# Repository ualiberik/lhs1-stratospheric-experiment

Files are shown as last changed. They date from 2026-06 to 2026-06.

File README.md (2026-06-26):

# LHS-1 Stratospheric Experiment: 26.073B

## Overview
This project is the stratospheric experiment for a high-altitude balloon flight. The experiment studies thermal insulation efficiency of lunar regolith (simulant) collecting important data for the future colonization of the Moon. The experiment was selected by iEDU Cubes in Space program for the flight on the NASA RB-11 high-altitude balloon.

&nbsp;

<div align="center">
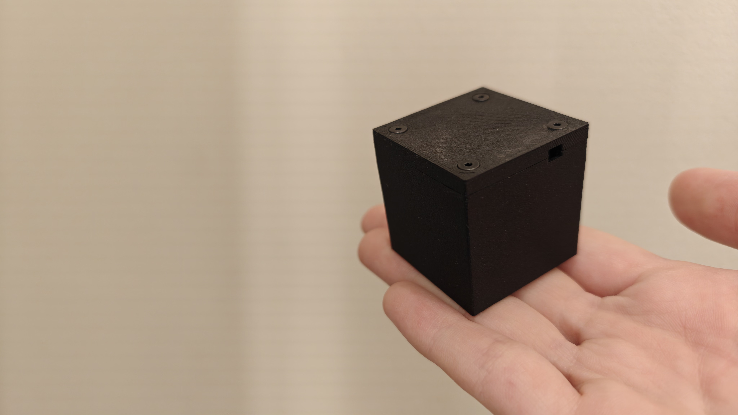
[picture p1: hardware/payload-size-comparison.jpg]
Payload Cubes Size Comparison
  
  <br>
  <em>Payload Cube Size Comparison</em>
</div>

&nbsp;

## Status
The ground experiments were conducted and the payload cube is fully ready for flight.

## Experiment Title
Thermal Insulation Efficiency of LHS-1 Lunar
Regolith Simulant as a Material for Lunar Habitats
in Stratospheric Near-Vacuum Conditions.

## Problem Statement
NASA and all the international space agencies highly
advocate the use of In-Situ Resource Utilization (ISRU), especially utilizing the lunar regolith as the main
material in the 3D printing of habitats. 

The main problem with the use of regolith in this regard is the alteration
in the thermal insulation capabilities of the regolith when it is exposed to vacuum conditions. This makes
regolith potentially an excellent insulator, but its exact performance in near-vacuum has not been sufficiently
tested under dynamic flight conditions on Earth. 

This gap is confirmed by reliable sources: Exolith Lab
(2023) LHS-1 Lunar Highlands Simulant Fact Sheet, NASA (2022) Lunar Surface Innovation Initiative – ISRU
Focus Area, and Zacny et al. (2012) “Lunar Regolith Mechanics and Its Relevance to ISRU” (Earth and Space
2012, ASCE).

## Hypothesis
_**IF**_ a high-accuracy temperature sensor (+-0.25°C accuracy, MCP9808) exposed to extremely low
temperatures (-50 °C to -60°C) and near-vacuum atmospheric pressure (0.01 ~ 0.1 atm corresponding to 15 -
25 km altitude) during a stratospheric balloon flight is shielded by 3-8 mm of lunar highlands regolith simulant
(LHS-1, with bulk density ~1.6 g/cm3),

_**THEN**_ the temperature drop under the protection of the regolith will be at least 30 - 50% slower (over a multi-hour exposure period), compared to an unprotected ambient sensor (BMP-388), proving the usefulness of
lunar regolith as a thermal insulation and shielding material for lunar surface bases,

_**BECAUSE**_ the extremely low atmospheric pressure (0.01 atm) will remove air between regolith particles,
significantly decreasing the efficiency of convective heat transfer and the overall thermal conductivity of the
regolith.

## Variables

### Independent Variables
1. **External temperature (°C):** BMP-388 sensor measures it during flight. It directly affects the
under-regolith temperatures and launches the cooling process, imitating nightfall on the Moon.

2. **Atmospheric pressure (Pa):** BMP-388 sensor measures it during flight. The decrease of atmospheric
pressure brings experiment closer to the lunar conditions and affects regolith’s thermal insulation
properties.

The experiment has 2 independent variables. However, they do not interfere with each other: the decrease of
external temperature is a trigger of cooling. Analysis compares it with under-regolith temperature, while the
atmospheric pressure defines how effectively the regolith shield works.

### Dependent Variables
1. **Under-regolith temperature (°C):** MCP9808 temperature sensor measures it during flight. It is the
internal temperature isolated by the regolith shield.

## Methodology

5 datasets will be collected:

1. **The flight dataset** — main data collected from the RB-11 flight in stratospheric conditions.

2. **No regolith configuration (atmosphere)** — defines baseline difference between sensors in 1 atmosphere conditions.

3. **No regolith configuration (near-vacuum)** — defines baseline between sensors in vacuum chamber conditions.

4. **Regolith configuration (atmosphere)** — defines regolith's contribution to thermal conductivity in 1 atmosphere conditions.

5. **Regolith configuration (near-vacuum)** — defines regolith's contribution to thermal conductivity in vacuum chamber conditions — the most close to the real flight test.

## Experiment Design

The experiment studies thermal insulation properties of lunar regolith simulant LHS-1 in stratospheric
conditions being launched on a balloon. The experiment components will be divided into 3 groups:

1. **Basic electronics group** — includes Adafruit ESP32-S3 microcontroller and Li-ion Charger. It controls
other electronics, saves data, and supplies power. ESP32-S3 microcontroller collects and writes data
once a second during flight and saves it on its own.

2. **Experimental group** — includes Adafruit MCP9808 temperature sensor and LHS-1 (Lunar Highlands
Simulant, then will be called “regolith”, “simulant”, “lunar dust”, etc.) shield. Sensor measures
dependent variable (under-regolith temperature). The regolith shield represents the main point of the
experiment, covering the sensor and protecting it from cooling.

3. **Control group** — includes Adafruit BMP388 atmospheric pressure and temperature sensor. It measures
independent variables (external temperature, atmospheric pressure) and plays the role of a control
group being not protected by a regolith shield.

The 3D-printed PET-G (Polyethylene Terephthalate Glyco — one of the plastics used for 3D-printing) cube payload cube contains all 3 groups providing construction rigidity and allowing mount components.

&nbsp;

<div align="center">
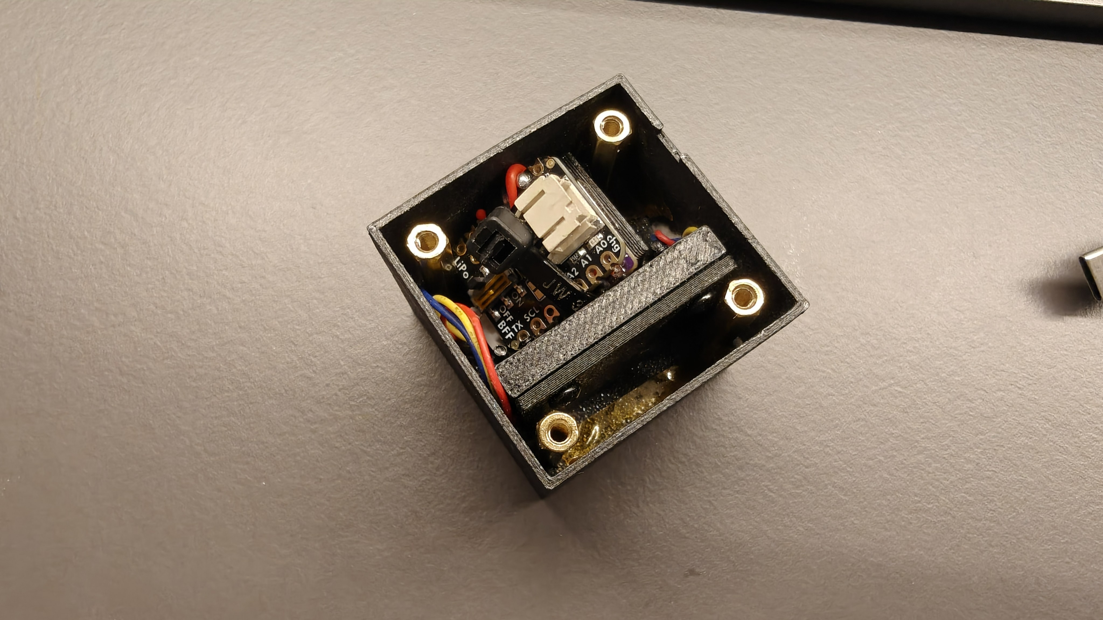
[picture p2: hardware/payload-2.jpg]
Payload Cube with Lid Opened
  
  <br>
  <em>Payload Cube with Lid Opened</em>
</div>

&nbsp;

## Repository Structure
```text
lhs1-stratospheric-experiment/
├── README.md
├── LICENSE
├── firmware/
│   ├── ion_2026_berikov/     # main flight firmware
│   ├── flashutil/            # flash management
│   └── ion_flash_dumper/     # data download
├── cad/
│   ├── stl/
│   ├── step/
│   └── renders/
├── hardware/
├── data/
│   ├── exp01-flight/
│   ├── exp02-no-reg-atm/
│   ├── exp03-no-reg-vac/
│   ├── exp04-reg-atm/
│   └── exp05-reg-vac/
├── analysis-scripts/
├── docs/
│   ├── results-summary.md
│   └── experiment-configs/
└── assets/
```
## Author Contributions
1. **Uali Berik** — Conceptualization, Methodology, Mechanical design (CAD),
   Software (firmware), Hardware integration, Validation, Writing,
   Project administration.

2. **Arlan Tairov** — Problem statement, Background research.

3. **Amina Toxankyzy** — Communication plan, Documentation of assembly process.

4. **Nurzhan Kunakbayev** — Safety, Analysis plan.

5. **Arman Temirbulatov** — Assembly support.

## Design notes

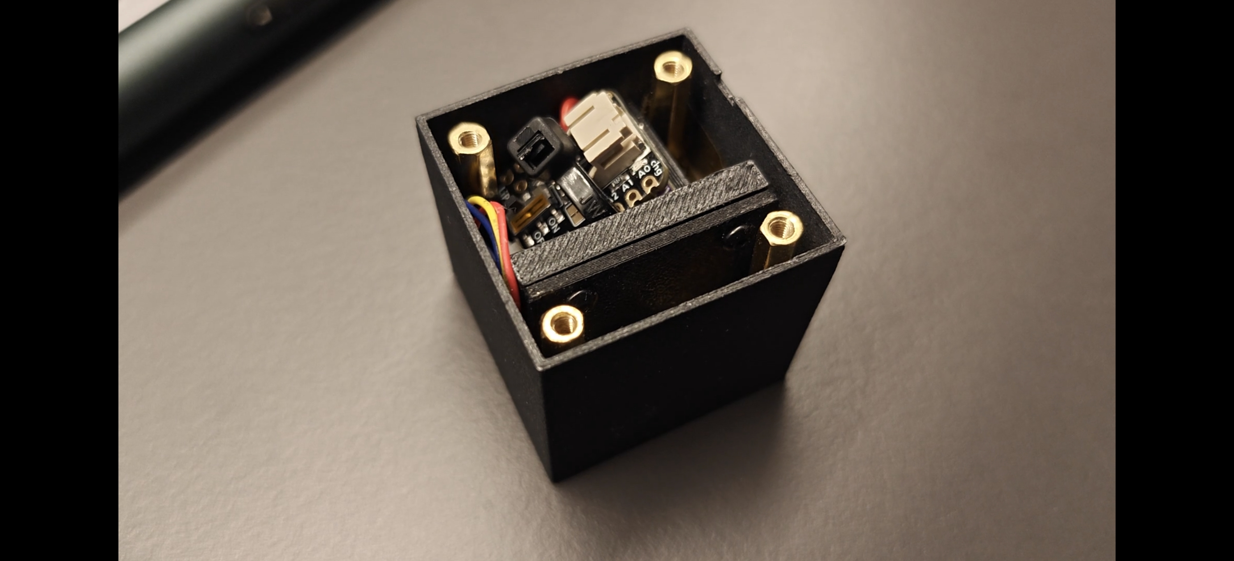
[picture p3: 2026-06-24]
hardware/payload-1.jpg

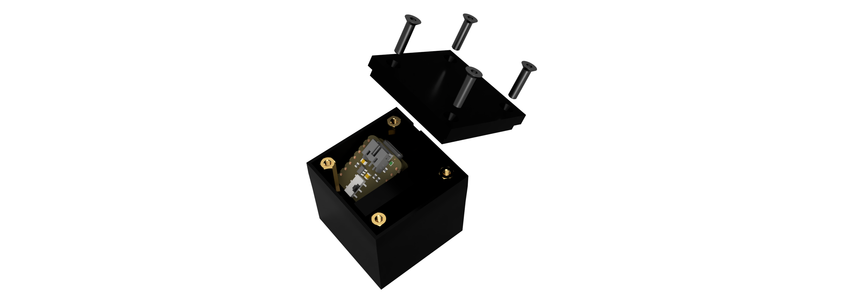
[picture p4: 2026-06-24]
cad/renders/lid-opened.png

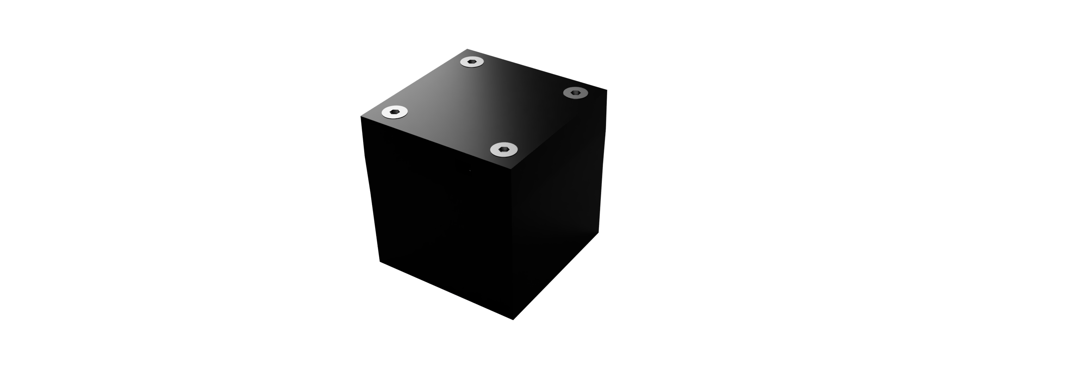
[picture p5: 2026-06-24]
cad/renders/payload-cube.png

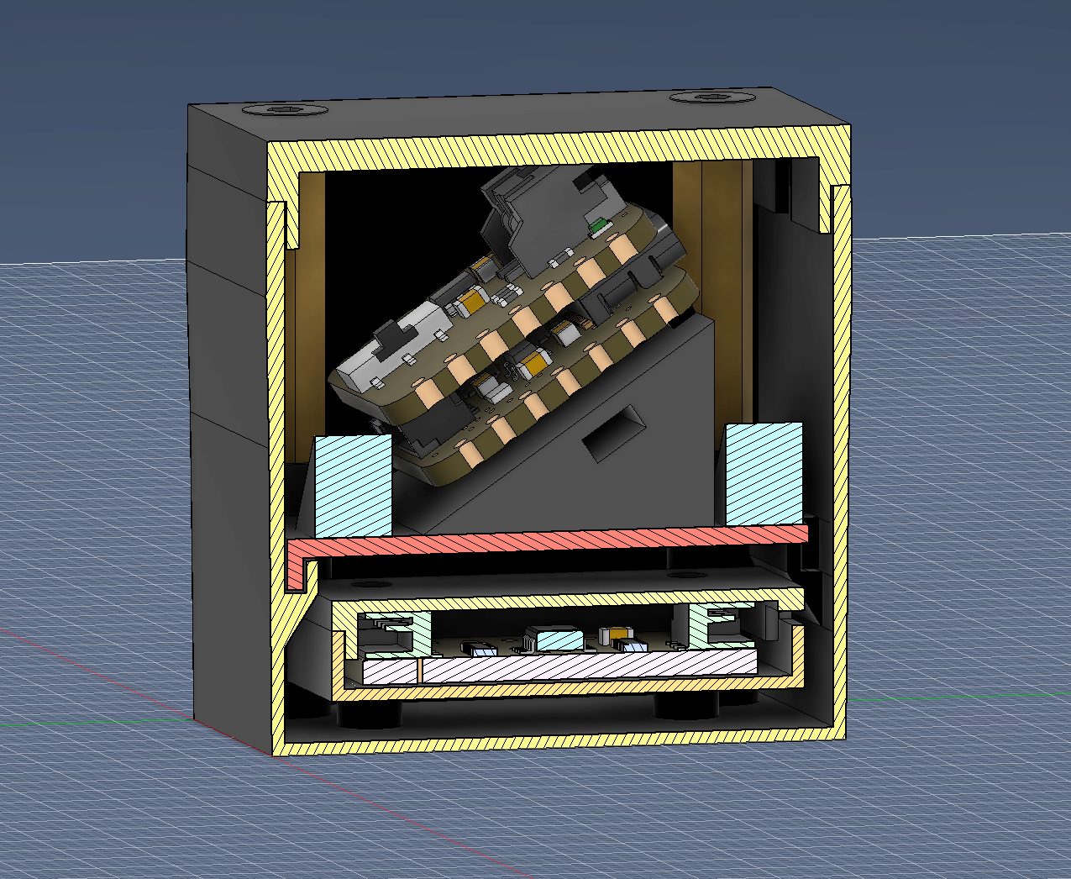
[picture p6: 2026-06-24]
cad/renders/payload-cube-in-section.png

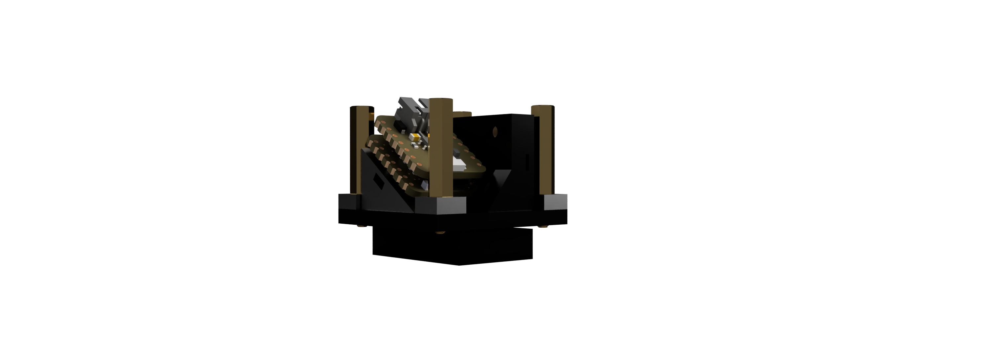
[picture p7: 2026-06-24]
cad/renders/payload-cube-inside.png

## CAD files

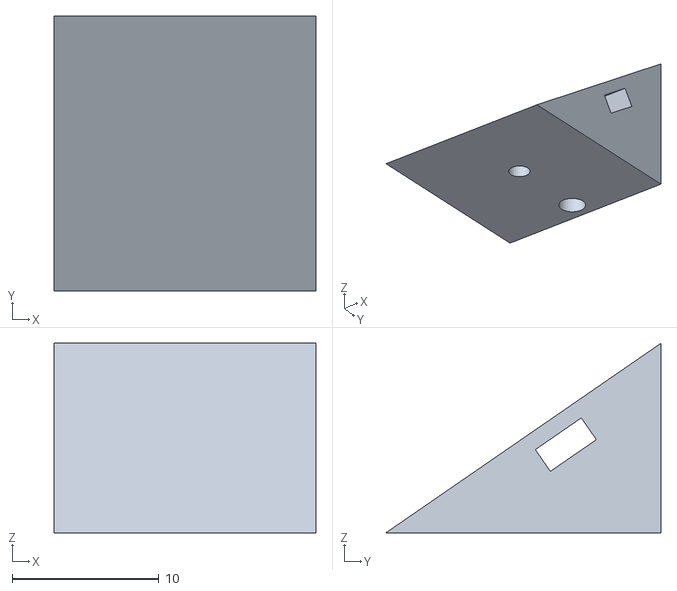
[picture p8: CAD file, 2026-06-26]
cad/stl/rack.stl
17.8 x 18.7 x 12.9

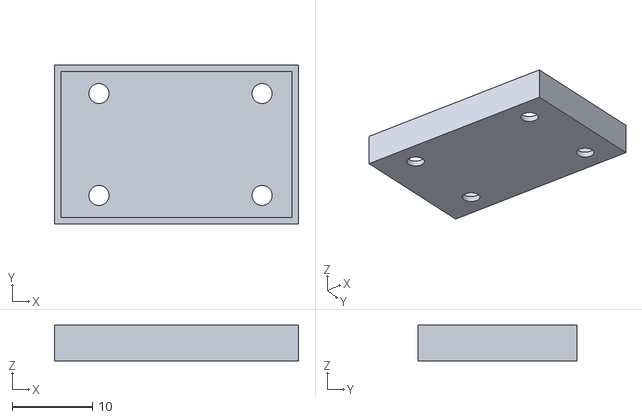
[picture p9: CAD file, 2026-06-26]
cad/stl/mcp-capsule.stl
30.4 x 19.8 x 4.43

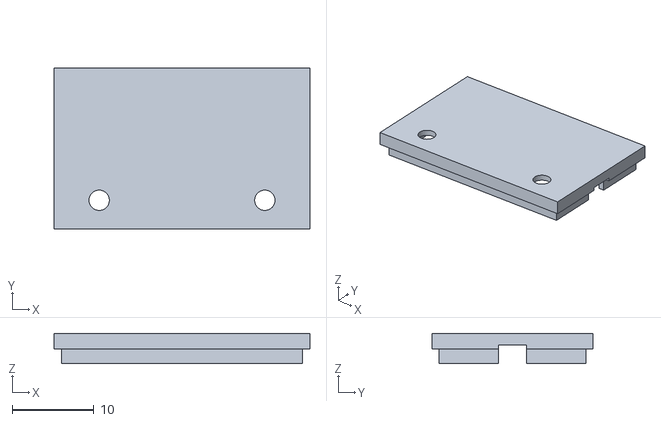
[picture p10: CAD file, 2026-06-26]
cad/stl/bmp-capsule-lid.stl
31.4 x 19.8 x 3.70

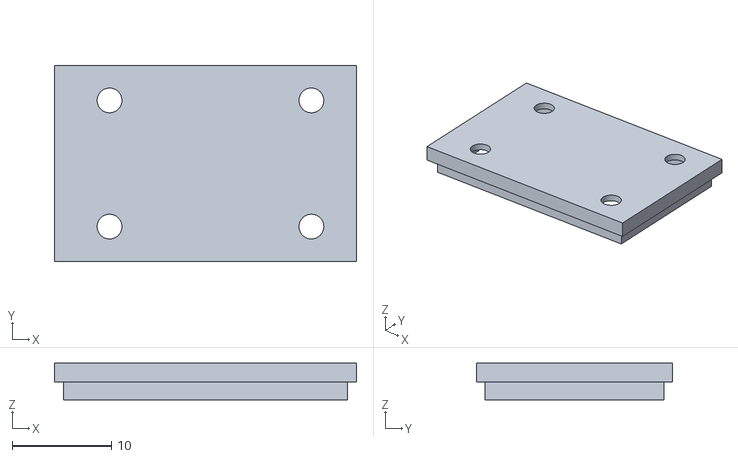
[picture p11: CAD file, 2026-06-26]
cad/stl/mcp-capsule-lid.stl
30.4 x 19.8 x 3.70

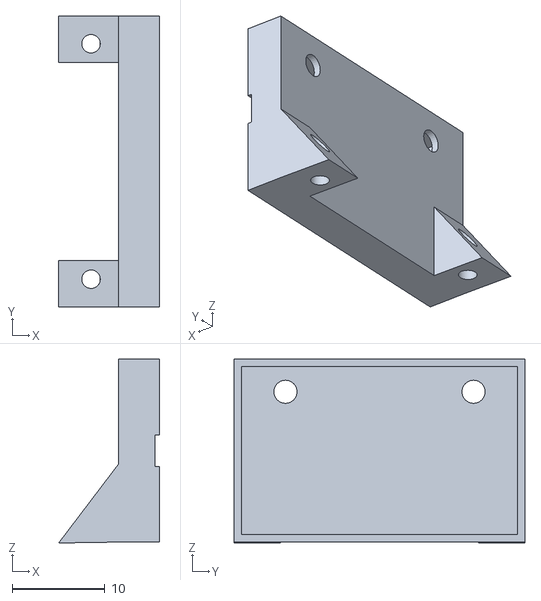
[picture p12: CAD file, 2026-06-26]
cad/stl/bmp-capsule.stl
10.9 x 31.4 x 19.9

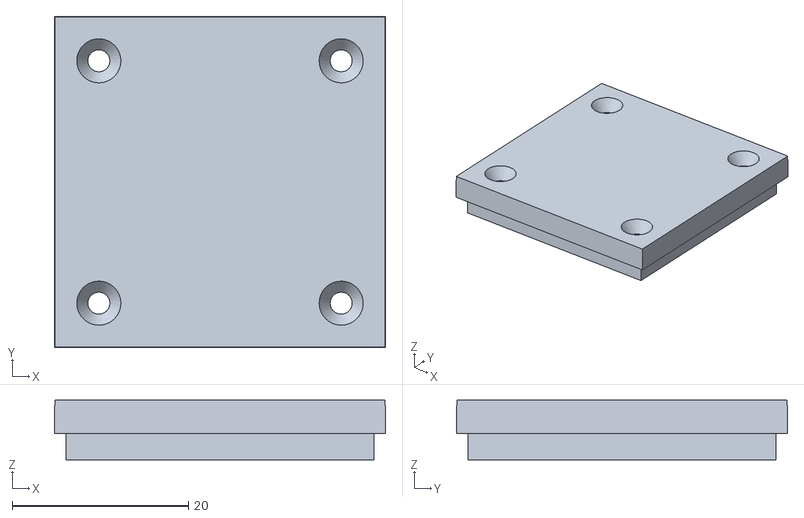
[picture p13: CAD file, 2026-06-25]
cad/stl/payload-cube-lid.stl
37.6 x 37.6 x 6.80

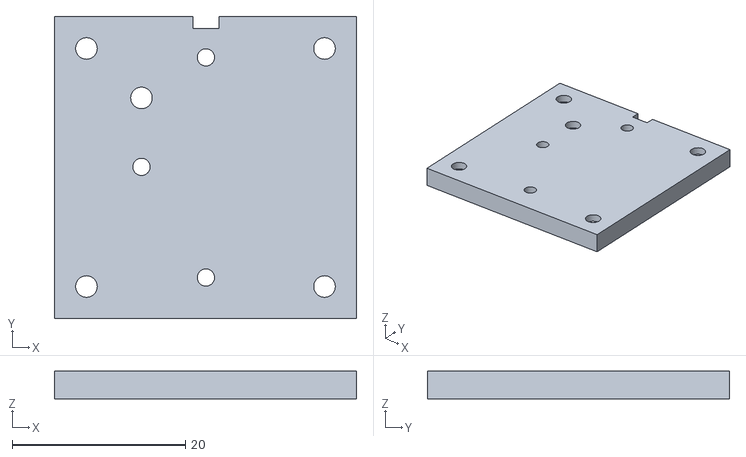
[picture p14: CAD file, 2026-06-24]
cad/stl/Plate.stl
34.9 x 34.9 x 3.20

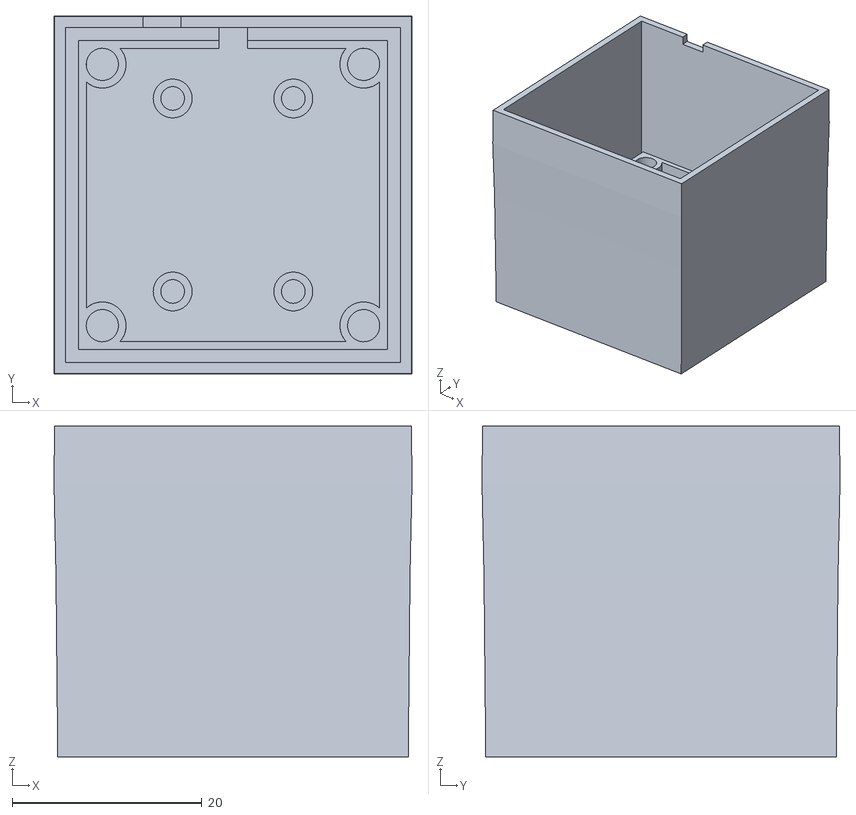
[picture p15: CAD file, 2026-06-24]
cad/stl/payload-cube.stl
37.7 x 37.7 x 34.8

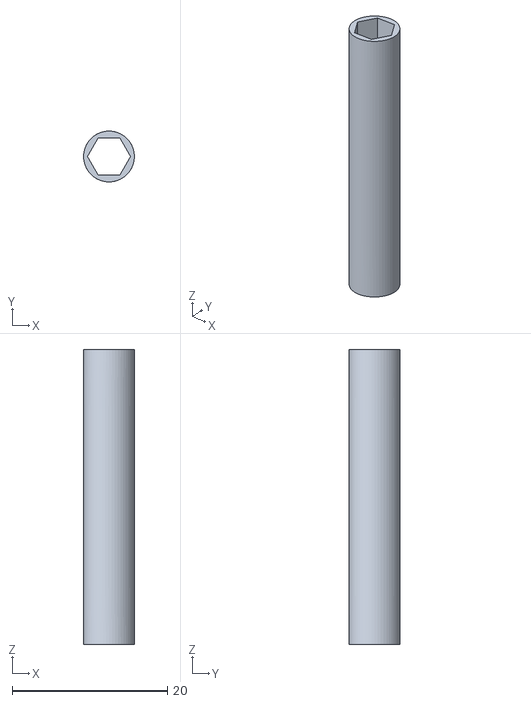
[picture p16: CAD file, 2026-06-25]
cad/stl/standoff-screwer.stl
6.55 x 6.55 x 38.0

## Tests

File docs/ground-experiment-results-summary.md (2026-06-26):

# LHS-1 Regolith Thermal Insulation — Ground Experiment Results

## Overview

Four bench experiments were conducted to characterize the thermal insulation effect of
LHS-1 Lunar Highlands Simulant regolith under atmospheric and near-vacuum conditions.
Cooling curves were fitted to Newton's law of cooling:

```
T(t) = T_amb + A × exp(−t / τ)
```

The primary metric is the **insulation ratio R = τ_mcp / τ_bmp**, where:
- τ_mcp — cooling time constant of the MCP9808 sensor (under regolith, or exposed)
- τ_bmp — cooling time constant of the BMP388 sensor (external reference)

R > 1 means the regolith-shielded sensor cools slower than the reference → insulation effect.

## Hardware

| Config | MCU | Firmware |
|---|---|---|
| EXP-04, EXP-05 | Adafruit ESP32-S3 Feather | ion_2026_berikov |
| EXP-02, EXP-03 | ESP32-C6 SuperMini | ion_no-regolith_c6 |

**Burst structure:** 60 s awake (600 samples at 100 ms) → 60 s sleep → repeat. Cycle = 120 s.

## Results

| Experiment | Conditions | τ_bmp (s) | τ_mcp (s) | R |
|---|---|---|---|---|
| EXP-02 | No regolith, atmosphere | 645 ± 13 | 645 ± 19 | **0.999** |
| EXP-04 | Regolith, atmosphere | 937 ± 14 | 1021 ± 24 | **1.090** |
| EXP-03 | No regolith, near-vacuum (~20 hPa) | 751 ± 15 | 709 ± 18 | **0.945** |
| EXP-05 | Regolith, near-vacuum (~25 hPa) | 879 ± 15 | 905 ± 27 | **1.029** |

EXP-04: 4 runs performed; run 4 used for final fit.  
EXP-05: run 1 discarded (unstable vacuum); run 2 used.

## Key Findings

**Net regolith contribution:**

| Medium | Δ = R_regolith − R_baseline | Interpretation |
|---|---|---|
| Atmosphere | 1.090 − 0.999 = **+0.091** | Regolith slows MCP cooling by ~9% |
| Near-vacuum | 1.029 − 0.945 = **+0.084** | Regolith slows MCP cooling by ~8% |

Both values are positive: **regolith provides measurable thermal insulation in both environments.**

The difference between Δ_atm and Δ_vac (0.007) is smaller than the propagated
uncertainty (~±0.047), so whether vacuum enhances the insulation effect is statistically
inconclusive at this sample size.

**Baseline asymmetry in vacuum (EXP-03, R = 0.945):** without regolith, the MCP9808
cools faster than the BMP388 under near-vacuum conditions. This reflects differences in
radiative coupling between the two sensors in the absence of convection, and is absent
at atmospheric pressure (EXP-02, R = 0.999).

## Firmware Notes

An I2C bus recovery sequence (9 SCL clock pulses before `Wire.begin()`, per NXP UM10204
§3.1.16) was identified and tested during bench experiments to prevent sensor
initialization failures after deep sleep.

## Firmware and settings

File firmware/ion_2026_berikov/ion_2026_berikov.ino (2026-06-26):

//
//  The MIT License (MIT)
//
// Copyright (c) 2026 Frank Peri for Cubes in Space
//
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
// Update History
// 11/26/2023:
// Fork that combines ION_Circularbuffertest.ino + ION_FLIGHT_2024.ino
// 1: refactored to use FSM library - significanly simplifies logic
// 2: first attempt to push Rocket and Balloon codes together - #defines used to determine if LORA and GPS enabled
// 3: similarly, combining M0, nRF52 and ESP32 elements into one codesets - complete - established #if defined's to block code (LED vs. NEOPIXEL)
// 4: settled on original IMU from balloon 2023 mission (LSM6D+LIS3), rather than using BNOxx - added Adafruit AHRS to get RPY
// 5: using RTC from balloon - added logic for deciding if RTC or GPS will be used for timing if both RTC and GPS installed
// 6: refined buffer from ION_Circularbuffertest.ino to be more efficient - moving pointers rather than using memcopy
// 7: added functions to simulate ax, deltaH variations for rocket
//
// WORK AHEAD:
// 1 - decide how to add FLOAT state to balloon, in lieu of DEPLOY for rocket - are they the same? - CLOSED: removed deploy state from balloon
// 2 - close various ACTIONs throughout - CLOSED
// 3 - simple and elegant way to pull data off FLASH for analysis - currently can list to Serial, need to capture to a file - CLOSED: added a web interface qith ability to download files from FLASH - CLOSED, using web
//
// 09/18/2024: Updates - FSM_demo_copy_20240918123502_copy_20240918123559
// 1: evaluate triggers for FSM that transition from Standby to Launch based upon experience handling Rocket at FF 2024 (too easy to trogger launch during routine handling)
//
// 10/08/24: Update - event_demo <- FSM_demo_copy_20240918123502
// refactoring into event-driven logic rather than states - triggers for transitions are the same, simply using the already existing flightStatus register to check and set events
// FSM worked fine, but was overkill. Events include: launch, deploy, land
// System boots into Command Mode (flightStatus = 0x80) which disables any event checking. CmdMode allows file operations (download and delete)
// Must command into Standby (flightStatus = 0x00) to enable event checking
// Command Mode is used Modes include: command, standby, missionend. Note I have not implemented groundmode nor SIM in this update.
//
// 6/2025 updates "event_demo_copy.ino"
// a) updated trigger logic
// b) removed Ambient Sensor measurement (all references to steinhart commented out - simply not practical to incluide external thermistors on ION
// c) Integrated Calibration code into this codeset (it was integrated in earlier versions, but pulled to reduce code size). Will examine code size before
// deciding to include Calibration here. Pulling code from ION_Calibration_FINAL_Rev1. Calibration is assessible via the serial processor (enter Y within the first 8 seconds of
// poweron). Had to reorganize setup() to init flash and cal before calling calibration during Serial poll sequence - thereby nulling some Serial outputs
// d) added SerialhandleFileList routine to setup since this seems to fix the random flash errors in prior versions
// e) using elapsedmillis() for getdata routine - seems to avoid data overrun errors - future work: incorporate elapsedmillis for other timers (writedata and LoRA)
// f) Minor updates to indicator light notifications
//
// Summary of indicator notifications:
// err(2, RED) - calibration routine error - rare - CONSIDER DELETING THIS NOTIFICATION 6-3-2025
// err(2, RED) - Failed to sync time error
// err(3, RED) - file open error
// err(4, RED) - flash file system error
// err(5, RED) - Wire interface error - rare - CONSIDER DELETING THIS NOTIFICATION 6-3-2025
// err(2, YELLOW) - IMU, BMP or RTC error - likely a wiring error
// err(3, YELLOW) - LoRA error
//
// Summary of status indicator:
// DKGREEN Steady - in STANDBY mode
// MAGENTA Steady - in CMD mode
// ORANGE Steady - launched
// PINK Steady - deployed (float)
// WHITE Steady - landed
// YELLOW 1 blink repeat - post boot waiting on input to Serial (times out after 8 sec)
// BLUE Steady - GPS acquired time signal during setup()
//
// 7/24/25 updates: "event_demo_copy_copy_20250724232525.ino"
// Addresses two uncertainties 1) the 2025 mission has more ION's than battery capacity for full duration of the mission, therefore
// likely to run out of power before the mission completes, and 2) event triggers are not perfect, especially deploy (aka float) and
// land, therefore continue to collect and sync data to datafile and do not close file
//
// 1) added functionality to periodically save data to memory to ensure no data lost due to power outage - I did this for the SD card
//    version - don't know why I didn't consider this earlier
// 2) improved smoothing and derivative functions - using SavLay library to replace median filters
// 3) improved EVENT triggers
// 4) commented out closefile command in closeFile()
//
//  BASELINE FOR 2025 CiS BALLOONN MISSION and copied to ION_Balloon_Flight_2025-as-flown.ino
//
// Future work:
// 1) review EVENT triggers for Rocket - battery is less likely a problem for Rocket, so may uncomment closefile command
// 2) review dataMessage tht is transmitted to Groundstation - likely update to Groundstation required to decode dataMessage
// 3) update to determine 3D velocity
//
// 02/16/2026 update to simplify for 2026
// Starting with baseline: "event_demo_copy_copy_20250724232525_copy_20250803194217.ino"
// Motivation:
// - Use deep sleep function of esp32 to save battery and storage
// - simplify operations
// - eliminate EVENT triggers based upon flight regime changes (launch, float, land)
//
// Concept:
// Use esp32 deep sleep feature to save battery: sleep cycle: 1 min on, 10 min off
// 1) Boot
// 2) Start RTC, read uniqueID, prep memory, init sensors, etc
// 3) Start serial
// 4) Check serial
// 5a) if no serial input
// 5a1) open file for append
// 5a2) take data for 1 min, store in file, close file - NOTE 1 min TBR depending on measured power consumption
// 5a3) go to deep sleep for 14 min - NOTE 14 min TBR depending on measured power consumption
// 5a4) waking from deep-sleep returns to 2)
// 5b) if serial input (Y)
// 5b1) parse input: C for calibrate, W for webserver
// 5b2) After choosing C, start calibration then goto standby mode
// 5b1) After choosing W, infinte while loop around webserver (add a esp.reset to web interface)
// 5b2) process serial commmand as in prior version

// in serial mode can take data but not save data to memory
// all web functions as in prior version - allows for downloading data and reviewing data collection in RT

// 3/1/2026: changes to SdFat code broke webserver.h. This is documented at:
// https://github.com/greiman/SdFat/issues/337#issuecomment-949610330
// Beginning at about line 90 the following changes must be made to ArduinoFiles.h:
// ----- begin changes (note lines 90-93 are commented out and new definiotn for getName replaced)
// FROM:
// #ifndef DOXYGEN_SHOULD_SKIP_THIS
//   char* __attribute__((error("use getName(name, size)"))) name();
// #endif  // DOXYGEN_SHOULD_SKIP_THIS
//
// TO:
// //#ifndef DOXYGEN_SHOULD_SKIP_THIS
// //  char* __attribute__((error("use getName(name, size)"))) name();
// //#endif  // DOXYGEN_SHOULD_SKIP_THIS
//  char *name()
//  {
//    BaseFile::getName(m_name, sizeof(m_name));
//    return m_name;
//  }
//  char m_name[256];
// ----- end changes
//
// FUTURE WORK:
// 3/4/2026:
// 1) consider an error register. Baseline behavior is to terminate operation if an error arises (typically hw)
//    in some cases this is overkill - for example, a pmon error might be ok to proceed, noting that voltage measurements
//    will be inaccurate. Others may include calibration sw routine error, timesync error. Could look like:
//      uint8_t errorStatus = 0x00;
//  b     b      b         b      b      b      b      b
//  pmon  calsw  timesync  other  other  other  other  other
//  of course logging errors does no good if we can't read them, so the error register must be added to the datastream, so not a trivial change
//
//
// --------------------------- README ---------------------------
//
// In 2026, CiS offfered students the ability to change sensors for the balloon mission. Comments are added in code to indicate where changes to code must be made.
// Comments will be noted by: //@SENSOR
// We are not allowing changes to datastream so no sensors can be added, only swapped. This has an impact to mode changes if imu is delected (which is another good
// reason to eliminate that operational mode for balloon variant)
//

#if defined(ARDUINO_ADAFRUIT_FEATHER_ESP32S2) || defined(ARDUINO_ADAFRUIT_FEATHER_ESP32S3) || defined(ARDUINO_ADAFRUIT_FEATHER_ESP32S3_NOPSRAM) || defined(ARDUINO_ADAFRUIT_QTPY_ESP32S2) || defined(ARDUINO_ADAFRUIT_QTPY_ESP32S3_NOPSRAM) || defined(ARDUINO_ADAFRUIT_QTPY_ESP32S3)
//#include <driver/adc.h>  // for ESP32
#endif

#if defined(ADAFRUIT_FEATHER_M0) || defined(ADAFRUIT_FEATHER_M0_EXPRESS) || defined(ARDUINO_SAMD_FEATHER_M0)  // Feather M0 w/Radio
#include <avr/dtostrf.h>                                                                                      // for M0
#include <Fadinglight.h>                                                                                      // LED version
#endif

#include <SPI.h>
#include <SdFat.h>
#include <BMP388_DEV.h>                   //@SENSOR
#include <Adafruit_MCP9808.h>             //@SENSOR //@BERIKOV under-regolith temperature sensor (replaces IMU)
#include <Adafruit_Sensor.h>             //@BERIKOV provides sensors_event_t (was pulled in via IMU/AHRS headers)
//@BERIKOV IMU/magnetometer/AHRS not used in our configuration
//#include <Adafruit_LSM6DSOX.h>            //@SENSOR
//#include <Adafruit_LIS3MDL.h>             //@SENSOR
//#include <Adafruit_AHRS.h>                //@SENSOR
#include <Adafruit_Sensor_Calibration.h>  //@SENSOR
#include "Adafruit_LC709203F.h"
#include "Adafruit_MAX1704X.h"
#include <NeoFader.h>
#include <TimeLib.h>
#include <RTClib.h>
#include <ArduinoUniqueID.h>
#include <SparkFun_u-blox_GNSS_Arduino_Library.h>  //http://librarymanager/All#SparkFun_u-blox_GNSS - so many GPS libraries, I like this the best
#include <LoRa.h>
#include <Adafruit_SPIFlash.h>
#include <WiFi.h>
#include <WebServer.h>
#include <elapsedMillis.h>
#include <SavLayFilter.h>
#include <esp_wifi.h>

// necessary to address esp3.0.1 library changes - ugh
#define FILE_READ O_RDONLY
#define FILE_WRITE (O_RDWR | O_CREAT | O_AT_END)

//
// HARDWARE CONFIGURATION DEFINITIONS
//
#define BALLOON         // comment out for rocket version
//#define LORA_ENABLED  // uncomment for LoRa version only for Rocket
//#define GPS_ENABLED   // uncomment for GPS version only for Rocket

//
// status register definitions
//
#define LAUNCH 0      // bit 0 of flightStatus register (Rightmost bit) - indicates Launch detected
#define DEPLOY 1      // bit 1 of flightStatus register - indicates Deploy (or hard G) detected
#define LAND 2        // bit 2 of flightStatus register - indicates Landing detected
#define GPSFIX 3      // bit 3 of flightStatus register - indicates GPS fixed - informational only, not used for any event checking
#define MISSIONEND 4  // bit 4 of flightStatus register - indicates mission ended
#define UNUSED 5      // bit 5 of flightStatus register - unused
#define WRITEFLASH 6  // bit 6 of flightStatus register - 1 = write to FLASH storage: 0 = write to circular buffer
#define CMDMODE 7     // bit 7 of flightStatus register - indicates cmd mode
//  b         b          b        b             b         b         b           b
//  CmdMode   WriteFlash GndTest  missionEnd    GPSFix    landFlag  deployFlag  launchFlag

//
// HARDWARE PIN DEFINITIONS
//
#if defined(ARDUINO_ADAFRUIT_QTPY_ESP32S2) || defined(ARDUINO_ADAFRUIT_QTPY_ESP32S3_NOPSRAM) || defined(ARDUINO_ADAFRUIT_QTPY_ESP32S3)
#define LORA_CS A1
#define LORA_IRQ SDA
#define LORA_RESET SCL
#define VBATPIN A2  // analog pin for external battery voltage measurement on QT PY

// The first 2 here are boards w/radio BUILT-IN (Note the RP2040 board does not work with the BNO085 IMU)
// Boards using FeatherWing follow those. Note only nRF52840 express and adafruit_feather_m0 have been tested
#elif defined(__AVR_ATmega32U4__)  // Feather 32u4 w/Radio
#define LORA_CS 8
#define LORA_IRQ 7
#define LORA_RESET 4

#elif defined(ADAFRUIT_FEATHER_M0) || defined(ADAFRUIT_FEATHER_M0_EXPRESS) || defined(ARDUINO_SAMD_FEATHER_M0)  // Feather M0 w/Radio
#define LORA_CS 8
#define LORA_IRQ 3  // or is it 7?
#define LORA_RESET 4
#define VBATPIN A7  // internal voltage divider at this pin
#define VREF 3.3

#elif defined(__AVR_ATmega328P__)  // Feather 328P w/wing
#define LORA_CS 4                  //
#define LORA_IRQ 3                 //
#define LORA_RESET 2               // "A"

#elif defined(ESP8266)  // ESP8266 feather w/wing
#define LORA_CS 2       // "E"
#define LORA_IRQ 15     // "B"
#define LORA_RESET 16   // "D"

#elif defined(ARDUINO_ADAFRUIT_FEATHER_ESP32S2) || defined(ARDUINO_ADAFRUIT_FEATHER_ESP32S3) || defined(ARDUINO_ADAFRUIT_FEATHER_ESP32S3_NOPSRAM) || defined(ARDUINO_NRF52840_FEATHER) || defined(ARDUINO_NRF52840_FEATHER_SENSE)
#define LORA_CS 10     // "B"
#define LORA_IRQ 6     // "D"
#define LORA_RESET 11  // "A"
#define VBATPIN A6     // internal voltage divider at this pin for nRF52840, ESP32 use LC device
#define VREF 3.6

#elif defined(ESP32)  // ESP32 feather w/wing
#define LORA_CS 33    // "B"
#define LORA_IRQ 27   // "A"
#define LORA_RESET 13

#elif defined(ARDUINO_NRF52832_FEATHER)  // nRF52832 feather w/wing
#define LORA_CS 11                       // "B"
#define LORA_IRQ 31                      // "C"
#define LORA_RESET 7                     // "A"
#endif                                   // HW PIN DEFINITIONS
// end pin definitions

// deep sleep definitions
#define mS_TO_S_FACTOR 1000ULL     // Conversion factor for microseconds to seconds (ULL makes is an uint64_t)
#define uS_TO_S_FACTOR 1000000ULL  // Conversion factor for microseconds to seconds (ULL makes is an uint64_t)
#define SLEEP_TIME 600            // 600 sec (10 min) for sleep time while testing
#define AWAKE_TIME 60              // 60 sec to stay awake

// hardware structures
//@BERIKOV IMU/magnetometer not installed in our configuration
//Adafruit_LSM6DSOX lsm;  // IMU data structure           //@SENSOR
//Adafruit_LIS3MDL lis;   // magentometer data structure  //@SENSOR
Adafruit_MCP9808 mcp9808;          // under-regolith temperature sensor  //@SENSOR //@BERIKOV
float mcpTempUnderRegolith = 0.0;  // MCP9808 reading, routed into the ax datastream field  //@BERIKOV
Adafruit_LC709203F lc;  // only for ESP32-S3
Adafruit_MAX17048 maxlipo;
bool addr0x36 = true;  // MAX17048 i2c address

// sw structures
// QT PY uses Wire1 for STEMMA connector, so redefine Wire as Wire1 so sensor init statements don't need to change
#if defined(ARDUINO_ADAFRUIT_QTPY_ESP32S2) || defined(ARDUINO_ADAFRUIT_QTPY_ESP32S3_NOPSRAM) || defined(ARDUINO_ADAFRUIT_QTPY_ESP32S3)
#define WIRE Wire1
BMP388_DEV bmp388(SDA1, SCL1, WIRE);  // ESP QT PY uses Wire1 interface
#elif defined(ARDUINO_ADAFRUIT_FEATHER_ESP32S2) || defined(ARDUINO_ADAFRUIT_FEATHER_ESP32S3) || defined(ARDUINO_ADAFRUIT_FEATHER_ESP32S3_NOPSRAM)
#define WIRE Wire
BMP388_DEV bmp388(SDA, SCL, WIRE);
#endif

#if defined(ADAFRUIT_SENSOR_CALIBRATION_USE_EEPROM)
Adafruit_Sensor_Calibration_EEPROM cal;
#else
Adafruit_Sensor_Calibration_SDFat cal;
#endif

// love this timer library
elapsedMillis getDataTimer;
elapsedMillis flashWriteTimer;
elapsedMillis writeDataTimer;
elapsedMillis LoRaXmitTimer;

// data structures for sensor events (an Adafruit concept) when data is available) //@SENSOR
sensors_event_t accel_event, gyro_event, temp_event, mag_event;

// choose IMU filter: slower = better quality output
//@BERIKOV AHRS filter not used without IMU
//Adafruit_NXPSensorFusion filter;  // slowest - RPY seem more stable, doesn't seem "slow"  //@SENSOR
//Adafruit_Madgwick filter;  // faster than NXP
//Adafruit_Mahony filter;  // fastest/smalleset - RPY seem to drift with this filter

WebServer webserver(80);

#if defined(GPS_ENABLED)
SFE_UBLOX_GNSS myGNSS;
#endif

// various flash memory contructs
Adafruit_FlashTransport_ESP32 flashTransport;
Adafruit_SPIFlash flash(&flashTransport);
FatVolume fatfs;
File32 dataFile;
File32 root;
File32 file;

// real-time clock constructs
RTC_DS3231 rtc;
time_t getRtcTime();
time_t getGPSTime();
time_t launchTime;
tmElements_t tm;

// Offset hours from gps time (UTC)
//const int offset = 1;   // Central European Time
//const int offset = -5;  // Eastern Standard Time (USA)
const int offset = -4;  // Eastern Daylight Time (USA)
//const int offset = -8;  // Pacific Standard Time (USA)
//const int offset = -7;  // Pacific Daylight Time (USA)
//const char zone[] = "EST";  // "EDT"

// constant definitions
const uint16_t TIME_SYNC_INTERVAL = 300;  // 300 = 5 min, testing drift with long sync interval
const uint16_t SAMPLE_INTERVAL = 10;      // 10msec data sampling rate
const uint16_t FILTER_UPDATE_RATE_HZ = 100;
const uint16_t WRITE_BUFFER_LENGTH = 5;
const uint16_t MESSAGE_LENGTH = 270;
const uint16_t LAND_INTERVAL = 5000;

// various constants used by event logic
//#ifdef BALLOON - this approach superceded by implementing low power mode. No longer have to slow down write interval to save ram
//const uint16_t WRITE_INTERVAL = 10000;  // for balloon = 10 sec - remember, always sampling data at 100 Hz (10msec)
//const int8_t ALTITUDE_THRESHOLD = 100;  // 100 // start saving data above 100m for balloon
//const uint32_t SAVE_INTERVAL = 10000L;  // sync dataFile every 10 seconds
//#else
const uint16_t WRITE_INTERVAL = 100;  // for rocket launch = 0.1 sec - remember, always sampling data at 100 Hz (10msec)
const int8_t ALTITUDE_THRESHOLD = 1;  // start saving data above 1m for rocket
const uint32_t SAVE_INTERVAL = 500;   // sync dataFile every 500 msec
//#endif
const int8_t LAUNCH_THRESHOLD = 14;  // accel at rocket launch
const int8_t DEPLOY_THRESHOLD = 15;  // accel at rocket ejection charge
const int8_t ALTITUDE_ERROR = 1;     // deadband for measuring FLOAT event
const int8_t LAND_THRESHOLD = 0;     // delta altitude, not moving, therefore landed

#if defined(LORA_ENABLED)
const uint8_t localAddress = 0xDD;  // address of this device
const uint8_t destination = 0xBB;   // destination to send to
const uint32_t XMTRATE = 500;       // 500 msec
#endif

// variable definitions
uint32_t vBattery;                                      // external battery voltage

// sensor variable definitions                          //@SENSOR
float gx, gy, gz, roll, pitch, yaw;                     // 3-axis accels and rotations
float gravX, gravY, gravZ;                              // gravity vector = 1 if axis is pointing opposite gravity, -1 if axis is pointing toward gravity
float temperature, pressure, altitude, altitudeApogee;  // Create the temperature, pressure and altitude variables
float sealevelPressure;                                 // will be determined after boot
float daltitude;                                        // used for computed derivative
float padElevation;                                     // altitude at pad (prior to launch)
double doublealtitude;
double smoothaltitude;
double doublebattery;
double smoothbattery;
SavLayFilter altitudeSmoother(&doublealtitude, 0, 5);    // 5-point smoother
SavLayFilter altitudeDerivative(&smoothaltitude, 1, 7);  // Computes the first derivative of the altitude
SavLayFilter batterySmoother(&doublebattery, 0, 5);      // 5-point smoother

const byte numChars = 35;
char filename[numChars] = { 0 };
char endMarker = '\n';

char writeBuffer[WRITE_BUFFER_LENGTH][MESSAGE_LENGTH];  // circular buffer to store data prior to launch

uint8_t flightStatus = 0x00;                            // start in Standby
//  b         b          b        b             b         b         b           b
//  CmdMode   WriteFlash GndTest  missionEnd    GPSFix    landFlag  deployFlag  launchFlag

bool RTCOk = false;
bool GPSOk = false;
bool dumpFile = false;
bool listFiles = false;
#ifdef BALLOON
bool copiedBuffer = true;  // don't need circular buffer for BALLOON
#else
bool copiedBuffer = false;
#endif

RTC_DATA_ATTR int bootCount = 0;
RTC_DATA_ATTR bool baselinePressSet = false;   // save this in RTC memory to we don't recalc baseline pressure after waking from sleep
RTC_DATA_ATTR char datafilename[33] = "ION-";  // typ: ION-7CDFA1-20240129-182154.log

char actionfile[33];
char action[9];
char UniqueIDString[10];
char dateStr[16];  // YYYYMMDD-HHMMSS+terminator
char buff[22];     // temp array for rx/tx cmd strings

// indicator macros for different platforms
#if defined(ESP32) || defined(ARDUINO_ADAFRUIT_FEATHER_ESP32S2) || defined(ARDUINO_ADAFRUIT_FEATHER_ESP32S3) || defined(ARDUINO_ADAFRUIT_FEATHER_ESP32S3_NOPSRAM)
NeoFader neo;  // for ESP32
#else
Fadinglight led(LED_BUILTIN);                          // create instance of led for error codes for M0 that doesn't have NeoPixel
#endif
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
void loop() {
  getData();
  webserver.handleClient();
  neo.update();
}

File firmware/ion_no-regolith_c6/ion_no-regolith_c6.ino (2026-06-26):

// ion_no-regolith_c6.ino
// Bench-test firmware for ESP32-C6 SuperMini, no-regolith configuration.
// Sensors: BMP388 (temperature + pressure), MCP9808 (temperature, no regolith shield).
// No battery monitor. No LoRa. No GPS. No NeoPixel.
//
// Deep sleep cycle: AWAKE_TIME s collecting → SLEEP_TIME s sleeping → repeat.
// Data format: column positions match ion_2026_berikov so cooling_analysis.py works unchanged.
//   col 0: deviceID    col 1: status(0)   col 2: BMP temp   col 3: pressure
//   col 4: altitude    col 5: sealevel    col 6: MCP temp
//
// Serial command mode: press 'Y' within 8 s of boot.
//   L = list files   D = dump data file   X = delete data file   E = exit/restart
//
// Required libraries: BMP388_DEV, Adafruit_MCP9808, LittleFS (built into ESP32 Arduino core)

#include <Wire.h>
#include <BMP388_DEV.h>
#include <Adafruit_MCP9808.h>
#include <LittleFS.h>

// ── Timing ────────────────────────────────────────────────────────────────────
#define uS_TO_S_FACTOR 1000000ULL
#define mS_TO_S_FACTOR 1000UL
#define SLEEP_TIME     60     // seconds (flight value: 600)
#define AWAKE_TIME     60     // seconds
#define WRITE_INTERVAL 100    // ms between samples → 600 samples per burst
#define SERIAL_WAIT    8000   // ms to wait for Serial 'Y' on boot

// ── Pin definitions ───────────────────────────────────────────────────────────
// Adjust these to match your ESP32-C6 SuperMini board wiring.
#define LED_PIN 8    // built-in LED on many ESP32-C6 SuperMini boards
#define SDA_PIN 6    // I2C SDA
#define SCL_PIN 7    // I2C SCL

// ── Separator ─────────────────────────────────────────────────────────────────
// Must match SEPARATOR in cooling_analysis.py. Written at the start of each wakeup.
#define SEPARATOR "00000000-000000"

// ── Persistent state (survives deep sleep, cleared on power-off) ──────────────
RTC_DATA_ATTR int bootCount = 0;
RTC_DATA_ATTR bool baselinePressSet = false;
RTC_DATA_ATTR float savedSealevel = 1013.25f;

// ── Globals ───────────────────────────────────────────────────────────────────
BMP388_DEV bmp388;
Adafruit_MCP9808 mcp9808;

float temperature, pressure, altitude;
char deviceID[13];    // 12 hex chars from MAC + null
char datafilename[28];  // "/ION-XXXXXXXXXXXX.log"

// ── Helpers ───────────────────────────────────────────────────────────────────
void blinkLED(int n, int ms = 150) {
  for (int i = 0; i < n; i++) {
    digitalWrite(LED_PIN, HIGH); delay(ms);
    digitalWrite(LED_PIN, LOW);  delay(ms);
  }
}

void buildDeviceID() {
  uint64_t mac = ESP.getEfuseMac();
  snprintf(deviceID, sizeof(deviceID), "%04X%08X",
           (uint16_t)(mac >> 32), (uint32_t)mac);
}

// ── Serial command mode ───────────────────────────────────────────────────────
void serialCmdMode() {
  Serial.println(F("\n=== ION-C6 Command Mode ==="));
  Serial.printf("Data file: %s\n", datafilename);
  Serial.println(F("L = list files | D = dump data | X = delete data | E = exit/restart"));

  while (true) {
    while (!Serial.available()) {}
    char cmd = toupper(Serial.read());

    if (cmd == 'L') {
      File root = LittleFS.open("/");
      File f = root.openNextFile();
      while (f) {
        Serial.printf("  %-24s  %lu bytes\n", f.name(), (unsigned long)f.size());
        f = root.openNextFile();
      }
      root.close();

    } else if (cmd == 'D') {
      Serial.printf(">>> Dumping %s\n", datafilename);
      File f = LittleFS.open(datafilename, "r");
      if (f) {
        while (f.available()) Serial.write(f.read());
        f.close();
        Serial.println(F(">>> End of file"));
      } else {
        Serial.println(F("File not found."));
      }

    } else if (cmd == 'X') {
      LittleFS.remove(datafilename);
      Serial.printf("Deleted %s\n", datafilename);

    } else if (cmd == 'E') {
      Serial.println(F("Restarting..."));
      delay(100);
      ESP.restart();
    }
  }
}

// ── setup ─────────────────────────────────────────────────────────────────────
void setup() {
  ++bootCount;
  pinMode(LED_PIN, OUTPUT);
  blinkLED(1);  // signal: awake

  Wire.begin(SDA_PIN, SCL_PIN);

  if (!LittleFS.begin(true)) {
    blinkLED(5, 300);  // filesystem error
  }

  buildDeviceID();
  snprintf(datafilename, sizeof(datafilename), "/ION-%s.log", deviceID);

  esp_sleep_enable_timer_wakeup((uint64_t)SLEEP_TIME * uS_TO_S_FACTOR);

  // Init sensors
  if (!bmp388.begin(NORMAL_MODE, OVERSAMPLING_X8, OVERSAMPLING_SKIP, IIR_FILTER_2, TIME_STANDBY_20MS)) {
    blinkLED(3, 300);  // BMP388 not found — data collection will produce no BMP rows
  }
  if (!mcp9808.begin(0x18, &Wire)) {
    blinkLED(2, 300);  // MCP9808 not found
  }
  mcp9808.setResolution(3);  // 0.0625 °C resolution

  // Wait for Serial 'Y'
  Serial.begin(115200);
  uint32_t t0 = millis();
  while (!Serial.available() && (millis() - t0) < SERIAL_WAIT) {}
  if (Serial.available() && toupper(Serial.peek()) == 'Y') {
    Serial.read();
    serialCmdMode();  // never returns — ends with ESP.restart()
  }

  // Baseline pressure: set once after first power-on, kept across deep-sleep cycles
  if (!baselinePressSet) {
    delay(200);
    if (bmp388.getMeasurements(temperature, pressure, altitude)) {
      savedSealevel = pressure;
      bmp388.setSeaLevelPressure(savedSealevel);
      baselinePressSet = true;
    }
  } else {
    bmp388.setSeaLevelPressure(savedSealevel);
  }

  // Open file and write separator (marks start of this wakeup burst)
  File dataFile = LittleFS.open(datafilename, "a");
  if (dataFile) {
    dataFile.println(SEPARATOR);
  }

  // Collect data for AWAKE_TIME seconds
  uint32_t awakeStart = millis();
  uint32_t lastWrite  = 0;

  while ((millis() - awakeStart) < (uint32_t)AWAKE_TIME * mS_TO_S_FACTOR) {
    uint32_t now = millis();
    if (now - lastWrite >= WRITE_INTERVAL) {
      lastWrite = now;

      float mcpTemp = mcp9808.readTempC();
      if (bmp388.getMeasurements(temperature, pressure, altitude)) {
        char line[96];
        // Columns: deviceID, status, bmp_temp, pressure, altitude, sealevel, mcp_temp
        snprintf(line, sizeof(line),
                 "%s,%u,%8.2f,%8.2f,%8.2f,%8.2f,%6.2f",
                 deviceID, 0u,
                 temperature, pressure, altitude, savedSealevel, mcpTemp);
        if (dataFile) dataFile.println(line);
      }
    }
  }

  if (dataFile) {
    dataFile.flush();
    dataFile.close();
  }

  blinkLED(2, 100);  // signal: going to sleep
  esp_deep_sleep_start();
}

void loop() {
  // Never reached — firmware sleeps in setup()
}

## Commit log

2026-06-24 Add .stl files
    [BMP Capsule.stl, BMP lid (1).stl, MCP capsule.stl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]
2026-06-25 Design standoff screwer
    [standoff-screwer.stl]
2026-06-25 Add heating time
2026-06-25 Fix payload cube lid cable notch
    [Payload cube lid.stl]
2026-06-25 Fix naming
    [bmp-capsule-lid.stl, bmp-capsule.stl, mcp-capsule-lid.stl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]
2026-06-25 Add analysis script; add processing results
    [exp04_burst_means.csv]
2026-06-25 Restructure data-related folders
    [exp04_burst_means.csv]
2026-06-25 Update analysis script; process run 2 data
    [exp04_reg-atm_2026-06-25_run1_burst-means.csv, exp04_reg-atm_2026-06-25_run2_burst-means.csv]
2026-06-25 Change protocol to power-on before heating in experiment configs
2026-06-25 Process exp04 run 3 data
    [exp04_reg-atm_2026-06-25_run3_burst-means.csv]
2026-06-26 Widen sensor capsules
    [bmp-capsule-lid.stl, bmp-capsule.stl, mcp-capsule-lid.stl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]
2026-06-26 Fix log date; process exp04 run 4
    [exp04_reg-atm_2026-06-26_run4_burst-means.csv]
2026-06-26 Widen zip tie hole in rack
    [rack.stl]
2026-06-26 Upload exp05 run 1 data log; process exp05 run 1 data
    [exp05_reg-vac_2026-06-26_run1_burst-means.csv]
2026-06-26 Add cooling division to analysis scripts; update processing results
    [exp05_reg-vac_2026-06-26_run1_burst-means.csv]
2026-06-26 Remove exp05 run 1 processing results
    [exp05_reg-vac_2026-06-26_run1_burst-means.csv]
2026-06-26 Add ion_no-regolith_c6
    [exp05_reg-vac_2026-06-26_run1_burst-means.csv]
2026-06-26 Clone ion code and add i2c recovery
2026-06-26 Process exp02 run 1 data
    [exp02_no-reg-atm_2026-06-26_run1_burst-means.csv]
2026-06-26 Process exp05 run 2 and exp03 run 1 data
    [exp03_no-reg-vac_2026-06-26_run1_burst-means.csv, exp05_reg-vac_2026-06-26_run2_burst-means.csv]
2026-06-26 Add multihour power-on test data log
2026-06-26 Add ground experiment results summary
2026-06-27 Add multihour power-on run 2 data log
